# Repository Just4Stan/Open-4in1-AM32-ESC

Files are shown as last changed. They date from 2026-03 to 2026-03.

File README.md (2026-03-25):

# Open 4-in-1 AM32 ESC

An open-source 4-in-1 ESC for FPV drones. Runs [AM32](https://github.com/AlkaMotors/AM32-MultiRotor-ESC-firmware) firmware, works with Betaflight over DShot. Designed in KiCad, ready to order from JLCPCB.

I made a video explaining how it works: https://www.youtube.com/watch?v=TwAmmPxOpTM




## Specs

| Parameter | Value |
|---|---|
| Firmware | AM32 |
| Input voltage | 3-6S LiPo (11.1-25.2V) |
| Continuous current | 35A per channel |
| MCU | AT32F421G8U7 (ARM Cortex-M4, 120MHz) |
| Gate driver | NSG2065Q (3-phase, FD6288Q-compatible) |
| MOSFETs | SP40N03GNJ (40V, 2.9mΩ) — optional FDMC8010DC (30V, 1.28mΩ) for premium builds |
| Current sensing | INA186A3IDCKR (100V/V) + 0.2mOhm shunt (165A max) |
| Protocol | DShot (Betaflight compatible) |
| Power supply | LMR51420YDDCR buck + TLV76733DRVR LDO |
| Connector | JST SM08B-SRSS-TB (Betaflight 8-pin standard) |
| PCB | 6-layer, 1oz copper, designed for JLCPCB PCBA |

## Alternative Components

The gate driver footprint is compatible with the entire FD6288Q clone family (27,000+ units combined stock across 7+ manufacturers) and the TI DRV8300. No PCB changes needed for any of them. Multiple pin-compatible MOSFET options are also available, including the FDMC8010DC (30V, 1.28mΩ) as a premium low-resistance option — 36% lower total phase resistance at the cost of reduced voltage headroom (7S max vs 8S+) and higher per-unit cost.

See [ALTERNATIVES.md](ALTERNATIVES.md) for the full list of pin-compatible gate drivers and MOSFETs with LCSC part numbers, specs, and stock levels.

## How it's built

The schematic is split into a main sheet and a sub-sheet that's reused 4 times — one per ESC channel.

The main sheet (`4in1ESC.kicad_sch`) has the power supply, current sensing, and the 8-pin connector. Each ESC channel (`ESC.kicad_sch`) has:
- AT32F421G8U7 running AM32 firmware
- NSG2065Q 3-phase gate driver with bootstrap caps
- 6x SP40N03GNJ MOSFETs in 3 half-bridges
- Back-EMF feedback network for sensorless commutation

## Project structure

```
4in1ESC.kicad_sch     Main schematic (power, sensing, connector)
ESC.kicad_sch         Single ESC channel (used 4x)
4in1ESC.kicad_pcb     PCB layout
4in1ESC.pretty/       Custom footprints
4in1ESC.3dshapes/     3D models (STEP files)
components.kicad_sym  Custom symbols (gate driver, connector, etc.)
datasheets/           Component datasheets
licensing/            Branding and third-party notices
tools/                Analysis scripts
```

## License

Licensed under [CERN-OHL-S-2.0](https://ohwr.org/cern_ohl_s_v2.txt). See [LICENSE](LICENSE) and [licensing/](licensing/) for branding and third-party notices.

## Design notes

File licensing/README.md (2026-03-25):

# Licensing Notes

This folder collects the repository-specific licensing and branding notes that sit alongside the root [LICENSE](../LICENSE) file.

Repository scope:

- Open 4-in-1 AM32 ESC hardware design files
- local footprints, symbols, and manufacturing data included in this repository

Primary project hardware license:

- `CERN-OHL-S-2.0` for the primary Open 4-in-1 ESC design and associated original project files

Related notes:

- [TRADEMARKS.md](TRADEMARKS.md) for branding and source-identifying use
- [THIRD_PARTY.md](THIRD_PARTY.md) for bundled upstream asset notices

The main `LICENSE` stays at the repository root so GitHub can detect the primary project license correctly.

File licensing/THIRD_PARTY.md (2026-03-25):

# Third-Party Assets

This repository's main hardware design is licensed under `CERN-OHL-S-2.0`, but some bundled assets may retain their own upstream notices or licenses.

Known third-party-licensed asset observed in the current repo state:

- `4in1ESC.3dshapes/QFN-28_L4.0-W4.0-P0.40-TL-EP2.4.step`
  - contains an embedded GNU General Public License notice in the file header

Practical rule:

- embedded upstream notices in individual third-party files remain relevant for those files
- the repository-level hardware license does not erase or replace those upstream notices

If more third-party library assets are intentionally bundled later, document them here.

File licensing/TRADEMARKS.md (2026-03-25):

# Trademarks And Branding

The primary Open 4-in-1 ESC hardware design in this repository is licensed under `CERN-OHL-S-2.0`.

Some bundled third-party assets may carry separate upstream notices. See [THIRD_PARTY.md](THIRD_PARTY.md).

That hardware license does **not** grant permission to use any project names, logos, packaging, product branding, or other source-identifying presentation from this repository in a way that implies official status, endorsement, certification, or authorization.

This means you may:

- make, modify, and sell hardware based on the licensed design files, subject to the repository license
- use factual, non-confusing descriptive statements about compatibility or design origin

This means you may not, without separate written permission:

- present your product as an official or authorized version of this project
- use project logos or branded packaging
- market your product in a way that is likely to confuse customers about who made it, tested it, certified it, or supports it

Examples of descriptive use that are generally acceptable:

- `based on the Open 4-in-1 AM32 ESC design`
- `compatible with the 20x20 Open 4-in-1 AM32 ESC layout`

Any permission to use branding for an official product, reseller arrangement, or certification program is separate from the open hardware license.

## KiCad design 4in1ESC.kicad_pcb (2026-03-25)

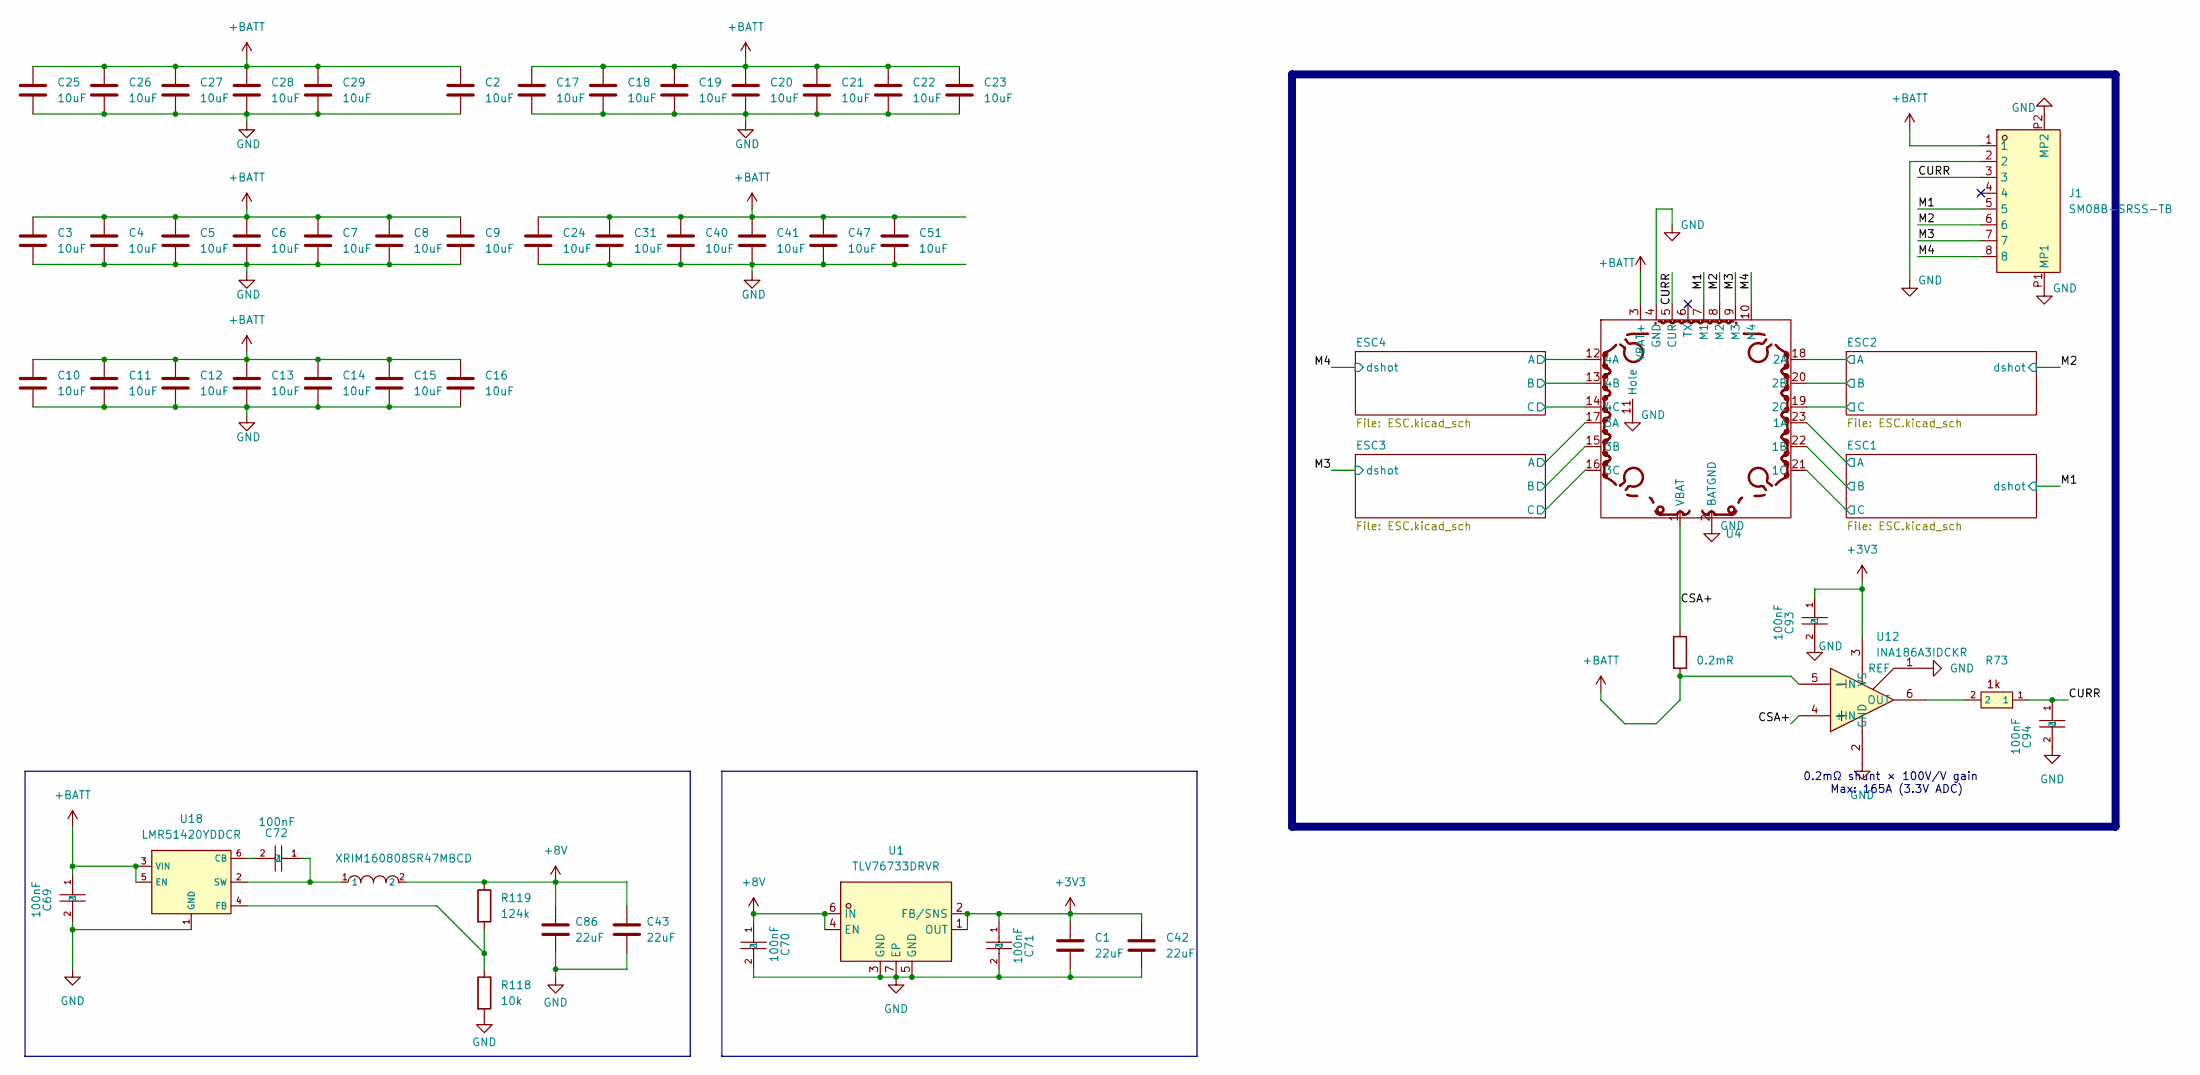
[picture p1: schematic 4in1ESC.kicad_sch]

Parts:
C1, C42: 22uF; C_0402_1005Metric; LCSC C105226
C2, C3, C4, C5, C6, C7, C8, C9, C10, C11, C12, C13, C14, C15, C16, C17, C18, C19, C20, C21, C22, C23, C24, C25, C26, C27, C28, C29, C31, C40, C41, C47, C51: 10uF; C_0805_2012Metric; LCSC C2932476
C43, C86: 22uF; C_0603_1608Metric; LCSC C2762594
C69, C70, C71, C72, C93, C94: 100nF; C_0201_0603Metric; LCSC C181043
J1: SM08B-SRSS-TB; JST_SM08B-SRSS-TB; LCSC C160407
R73: 1k; C_0201_0603Metric; LCSC C270365
R118: 10k; C_0201_0603Metric; LCSC C106225
R119: 124k; R_0201_0603Metric; LCSC C423759
Rsense1: 0.2mR; R_2512_6332Metric; LCSC C695806
U1: TLV76733DRVR; WSON-6_L2.0-W2.0-P0.65-TL-EP; LCSC C2848334
U4: 4in1ESC
U5: XRIM160808SR47MBCD; IND-SMD_L1.6-W0.8_FTC160865SR47MBCA; LCSC C48391583
U12: INA186A3IDCKR; SOT-363_SC-70-6; LCSC C2058245
U18: LMR51420YDDCR; SOT-23-6_L2.9-W1.6-P0.95-LS2.9-BL; LCSC C7296200

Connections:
+3V3: C1.2, C42.2, C71.1, C93.1, U1.1 (OUT), U1.2 (FB/SNS), U12.3 (VS); also elsewhere on the board
+8V: C43.1, C70.1, C86.1, R119.1, U1.4 (EN), U1.6 (IN), U5.2; also elsewhere on the board
+BATT: C2.1, C3.1, C4.1, C5.1, C6.1, C7.1, C8.1, C9.1, C10.1, C11.1, C12.1, C13.1, C14.1, C15.1, C16.1, C17.1, C18.1, C19.1, C20.1, C21.1, C22.1, C23.1, C24.1, C25.1, C26.1, C27.1, C28.1, C29.1, C31.1, C40.1, C41.1, C47.1, C51.1, C69.1, J1.1, Rsense1.2, U4.3 (VBAT+), U12.5 (-IN), U18.3 (VIN), U18.5 (EN); also elsewhere on the board
/CSA+: Rsense1.1, U4.1 (VBAT), U12.4 (+IN)
/CURR: C94.1, J1.3, R73.1, U4.5 (CUR)
/ESC1/MotorA: U4.23 (1A); also elsewhere on the board
/ESC1/MotorB: U4.22 (1B); also elsewhere on the board
/ESC1/MotorC: U4.21 (1C); also elsewhere on the board
/ESC2/MotorA: U4.18 (2A); also elsewhere on the board
/ESC2/MotorB: U4.20 (2B); also elsewhere on the board
/ESC2/MotorC: U4.19 (2C); also elsewhere on the board
/ESC3/MotorA: U4.17 (3A); also elsewhere on the board
/ESC3/MotorB: U4.15 (3B); also elsewhere on the board
/ESC3/MotorC: U4.16 (3C); also elsewhere on the board
/ESC4/MotorA: U4.12 (4A); also elsewhere on the board
/ESC4/MotorB: U4.13 (4B); also elsewhere on the board
/ESC4/MotorC: U4.14 (4C); also elsewhere on the board
/M1: J1.5, U4.7 (M1); also elsewhere on the board
/M2: J1.6, U4.8 (M2); also elsewhere on the board
/M3: J1.7, U4.9 (M3); also elsewhere on the board
/M4: J1.8, U4.10 (M4); also elsewhere on the board
GND: C1.1, C2.2, C3.2, C4.2, C5.2, C6.2, C7.2, C8.2, C9.2, C10.2, C11.2, C12.2, C13.2, C14.2, C15.2, C16.2, C17.2, C18.2, C19.2, C20.2, C21.2, C22.2, C23.2, C24.2, C25.2, C26.2, C27.2, C28.2, C29.2, C31.2, C40.2, C41.2, C42.1, C43.2, C47.2, C51.2, C69.2, C70.2, C71.2, C86.2, C93.2, C94.2, J1.2, J1.P1 (MP1), J1.P2 (MP2), R118.2, U1.3 (GND), U1.5 (GND), U1.7 (EP), U4.2 (BATGND), U4.4 (GND), U4.11 (Hole), U12.1 (REF), U12.2 (GND), U18.1 (GND); also elsewhere on the board
unnamed: R73.2, U12.6 (OUT)
unnamed: C72.2, U18.6 (CB)
unnamed: R118.1, R119.2, U18.4 (FB)
unnamed: C72.1, U5.1, U18.2 (SW)

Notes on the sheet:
0.2mΩ shunt × 100V/V gain Max: 165A (3.3V ADC)

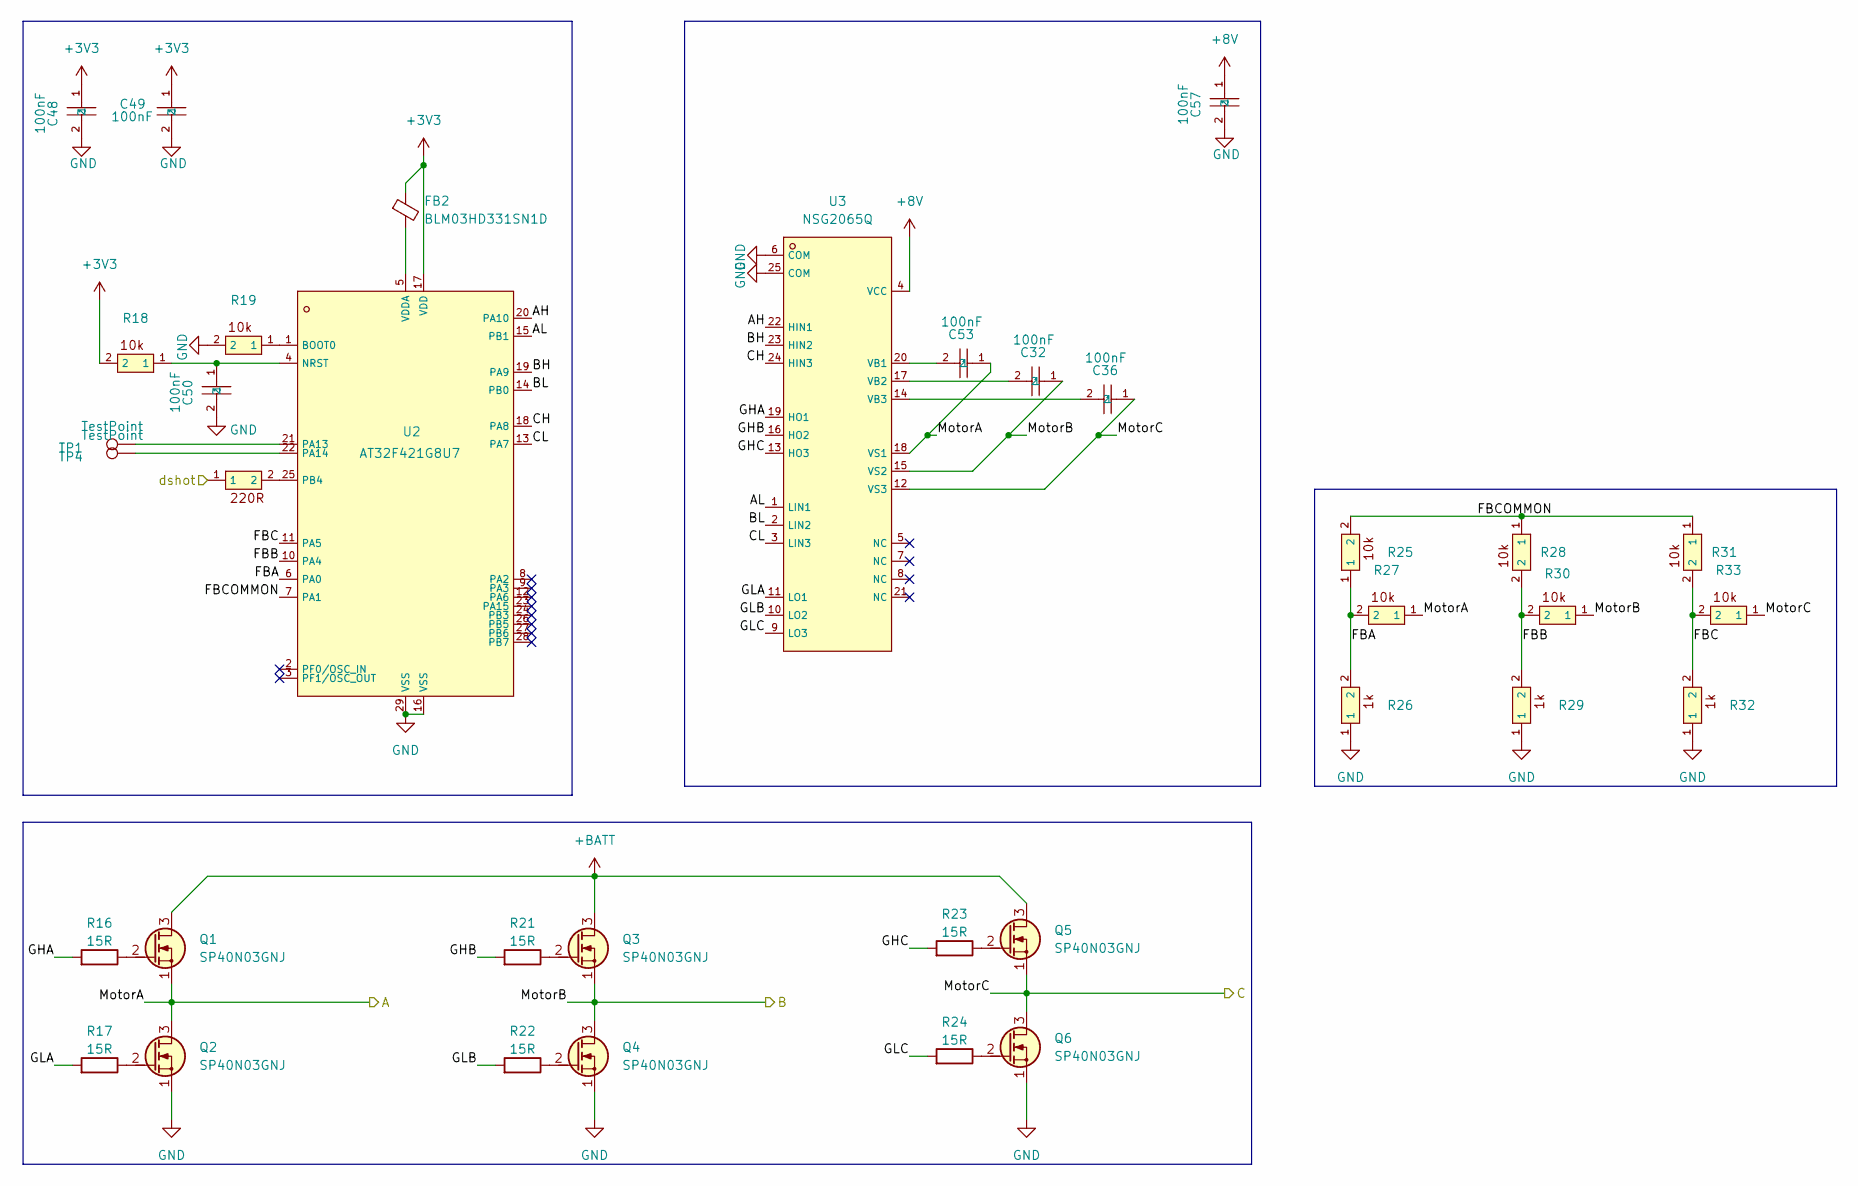
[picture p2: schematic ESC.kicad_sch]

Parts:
C32, C36, C53: 100nF; C_0402_1005Metric; LCSC C307331
C48, C49, C50, C57: 100nF; C_0201_0603Metric; LCSC C181043
FB2: BLM03HD331SN1D; L_0201_0603Metric; LCSC C440127
Q1, Q2, Q3, Q4, Q5, Q6: SP40N03GNJ; POWERPAK-1212-8_L3.0-W3.0-P0.65-LS3.3-BL; LCSC C22466709
R16, R17, R21, R22, R23, R24: 15R; C_0201_0603Metric; LCSC C473542
R18, R19, R25, R27, R28, R30, R31, R33: 10k; C_0201_0603Metric; LCSC C106225
R20: 220R; R_0201_0603Metric; LCSC C226468
R26, R29, R32: 1k; C_0201_0603Metric; LCSC C270365
TP1, TP4: TestPoint; TestPoint_Pad_D1.0mm
U2: AT32F421G8U7; QFN-28_L4.0-W4.0-P0.40-TL-EP2.4; LCSC C2765098
U3: NSG2065Q; QFN-24_L4.0-W4.0-P0.50-TL-EP2.8; LCSC C41414478

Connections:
+3V3: C48.1, C49.1, FB2.1, R18.2, U2.17 (VDD); also elsewhere on the board
+8V: C57.1, U3.4 (VCC); also elsewhere on the board
+BATT: Q1.3 (D), Q3.3 (D), Q5.3 (D); also elsewhere on the board
/ESC1/AH: U2.20 (PA10), U3.22 (HIN1)
/ESC1/AL: U2.15 (PB1), U3.1 (LIN1)
/ESC1/BH: U2.19 (PA9), U3.23 (HIN2)
/ESC1/BL: U2.14 (PB0), U3.2 (LIN2)
/ESC1/CH: U2.18 (PA8), U3.24 (HIN3)
/ESC1/CL: U2.13 (PA7), U3.3 (LIN3)
/ESC1/FBA: R25.1, R26.2, R27.2, U2.6 (PA0)
/ESC1/FBB: R28.2, R29.2, R30.2, U2.10 (PA4)
/ESC1/FBC: R31.2, R32.2, R33.2, U2.11 (PA5)
/ESC1/FBCOMMON: R25.2, R28.1, R31.1, U2.7 (PA1)
/ESC1/GHA: R16.1, U3.19 (HO1)
/ESC1/GHB: R21.1, U3.16 (HO2)
/ESC1/GHC: R23.1, U3.13 (HO3)
/ESC1/GLA: R17.1, U3.11 (LO1)
/ESC1/GLB: R22.1, U3.10 (LO2)
/ESC1/GLC: R24.1, U3.9 (LO3)
/ESC1/MotorA: C53.1, Q1.1 (S), Q2.3 (D), R27.1, U3.18 (VS1); also elsewhere on the board
/ESC1/MotorB: C32.1, Q3.1 (S), Q4.3 (D), R30.1, U3.15 (VS2); also elsewhere on the board
/ESC1/MotorC: C36.1, Q5.1 (S), Q6.3 (D), R33.1, U3.12 (VS3); also elsewhere on the board
/M1: R20.1; also elsewhere on the board
GND: C48.2, C49.2, C50.2, C57.2, Q2.1 (S), Q4.1 (S), Q6.1 (S), R19.2, R26.1, R29.1, R32.1, U2.16 (VSS), U2.29 (VSS), U3.6 (COM), U3.25 (COM); also elsewhere on the board
unnamed: Q1.2 (G), R16.2
unnamed: Q2.2 (G), R17.2
unnamed: Q3.2 (G), R21.2
unnamed: Q4.2 (G), R22.2
unnamed: Q5.2 (G), R23.2
unnamed: Q6.2 (G), R24.2
unnamed: R19.1, U2.1 (BOOT0)
unnamed: C50.1, R18.1, U2.4 (NRST)
unnamed: TP1.1, U2.21 (PA13)
unnamed: TP4.1, U2.22 (PA14)
unnamed: R20.2, U2.25 (PB4)
unnamed: FB2.2, U2.5 (VDDA)
unnamed: C53.2, U3.20 (VB1)
unnamed: C32.2, U3.17 (VB2)
unnamed: C36.2, U3.14 (VB3)

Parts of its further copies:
C33, C34, C35, C37, C38, C39, C59, C73, C83: 100nF; C_0402_1005Metric; LCSC C307331
C44, C45, C46, C63, C64, C65, C66, C77, C78, C79, C80, C88: 100nF; C_0201_0603Metric; LCSC C181043
FB1, FB3, FB4: BLM03HD331SN1D; L_0201_0603Metric; LCSC C440127
Q7, Q8, Q9, Q10, Q11, Q12, Q13, Q14, Q15, Q16, Q17, Q18, Q19, Q20, Q21, Q22, Q23, Q24: SP40N03GNJ; POWERPAK-1212-8_L3.0-W3.0-P0.65-LS3.3-BL; LCSC C22466709
R1, R2, R6, R7, R8, R9, R37, R38, R42, R43, R44, R45, R55, R56, R60, R61, R62, R63: 15R; C_0201_0603Metric; LCSC C473542
R3, R4, R10, R12, R13, R15, R34, R36, R39, R40, R46, R48, R49, R51, R52, R54, R57, R58, R64, R66, R67, R69, R70, R72: 10k; C_0201_0603Metric; LCSC C106225
R5, R41, R59: 220R; R_0201_0603Metric; LCSC C226468
R11, R14, R35, R47, R50, R53, R65, R68, R71: 1k; C_0201_0603Metric; LCSC C270365
TP2, TP3, TP5, TP6, TP7, TP8: TestPoint; TestPoint_Pad_D1.0mm
U6, U8, U10: AT32F421G8U7; QFN-28_L4.0-W4.0-P0.40-TL-EP2.4; LCSC C2765098
U7, U9, U11: NSG2065Q; QFN-24_L4.0-W4.0-P0.50-TL-EP2.8; LCSC C41414478

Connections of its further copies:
+3V3: C44.1, C45.1, C64.1, C65.1, C78.1, C79.1, FB1.1, FB3.1, FB4.1, R3.2, R39.2, R57.2, U6.17 (VDD), U8.17 (VDD), U10.17 (VDD); also elsewhere on the board
+8V: C63.1, C77.1, C88.1, U7.4 (VCC), U9.4 (VCC), U11.4 (VCC); also elsewhere on the board
+BATT: Q7.3 (D), Q9.3 (D), Q11.3 (D), Q13.3 (D), Q15.3 (D), Q17.3 (D), Q19.3 (D), Q21.3 (D), Q23.3 (D); also elsewhere on the board
/ESC2/AH: U6.20 (PA10), U7.22 (HIN1)
/ESC2/AL: U6.15 (PB1), U7.1 (LIN1)
/ESC2/BH: U6.19 (PA9), U7.23 (HIN2)
/ESC2/BL: U6.14 (PB0), U7.2 (LIN2)
/ESC2/CH: U6.18 (PA8), U7.24 (HIN3)
/ESC2/CL: U6.13 (PA7), U7.3 (LIN3)
/ESC2/FBA: R10.1, R11.2, R12.2, U6.6 (PA0)
/ESC2/FBB: R13.2, R14.2, R15.2, U6.10 (PA4)
/ESC2/FBC: R34.2, R35.2, R36.2, U6.11 (PA5)
/ESC2/FBCOMMON: R10.2, R13.1, R34.1, U6.7 (PA1)
/ESC2/GHA: R1.1, U7.19 (HO1)
/ESC2/GHB: R6.1, U7.16 (HO2)
/ESC2/GHC: R8.1, U7.13 (HO3)
/ESC2/GLA: R2.1, U7.11 (LO1)
/ESC2/GLB: R7.1, U7.10 (LO2)
/ESC2/GLC: R9.1, U7.9 (LO3)
/ESC2/MotorA: C59.1, Q7.1 (S), Q8.3 (D), R12.1, U7.18 (VS1); also elsewhere on the board
/ESC2/MotorB: C33.1, Q9.1 (S), Q10.3 (D), R15.1, U7.15 (VS2); also elsewhere on the board
/ESC2/MotorC: C37.1, Q11.1 (S), Q12.3 (D), R36.1, U7.12 (VS3); also elsewhere on the board
/ESC3/AH: U8.20 (PA10), U9.22 (HIN1)
/ESC3/AL: U8.15 (PB1), U9.1 (LIN1)
/ESC3/BH: U8.19 (PA9), U9.23 (HIN2)
/ESC3/BL: U8.14 (PB0), U9.2 (LIN2)
/ESC3/CH: U8.18 (PA8), U9.24 (HIN3)
/ESC3/CL: U8.13 (PA7), U9.3 (LIN3)
/ESC3/FBA: R46.1, R47.2, R48.2, U8.6 (PA0)
/ESC3/FBB: R49.2, R50.2, R51.2, U8.10 (PA4)
/ESC3/FBC: R52.2, R53.2, R54.2, U8.11 (PA5)
/ESC3/FBCOMMON: R46.2, R49.1, R52.1, U8.7 (PA1)
/ESC3/GHA: R37.1, U9.19 (HO1)
/ESC3/GHB: R42.1, U9.16 (HO2)
/ESC3/GHC: R44.1, U9.13 (HO3)
/ESC3/GLA: R38.1, U9.11 (LO1)
/ESC3/GLB: R43.1, U9.10 (LO2)
/ESC3/GLC: R45.1, U9.9 (LO3)
/ESC3/MotorA: C73.1, Q13.1 (S), Q14.3 (D), R48.1, U9.18 (VS1); also elsewhere on the board
/ESC3/MotorB: C34.1, Q15.1 (S), Q16.3 (D), R51.1, U9.15 (VS2); also elsewhere on the board
/ESC3/MotorC: C38.1, Q17.1 (S), Q18.3 (D), R54.1, U9.12 (VS3); also elsewhere on the board
/ESC4/AH: U10.20 (PA10), U11.22 (HIN1)
/ESC4/AL: U10.15 (PB1), U11.1 (LIN1)
/ESC4/BH: U10.19 (PA9), U11.23 (HIN2)
/ESC4/BL: U10.14 (PB0), U11.2 (LIN2)
/ESC4/CH: U10.18 (PA8), U11.24 (HIN3)
/ESC4/CL: U10.13 (PA7), U11.3 (LIN3)
/ESC4/FBA: R64.1, R65.2, R66.2, U10.6 (PA0)
/ESC4/FBB: R67.2, R68.2, R69.2, U10.10 (PA4)
/ESC4/FBC: R70.2, R71.2, R72.2, U10.11 (PA5)
/ESC4/FBCOMMON: R64.2, R67.1, R70.1, U10.7 (PA1)
/ESC4/GHA: R55.1, U11.19 (HO1)
/ESC4/GHB: R60.1, U11.16 (HO2)
/ESC4/GHC: R62.1, U11.13 (HO3)
/ESC4/GLA: R56.1, U11.11 (LO1)
/ESC4/GLB: R61.1, U11.10 (LO2)
/ESC4/GLC: R63.1, U11.9 (LO3)
/ESC4/MotorA: C83.1, Q19.1 (S), Q20.3 (D), R66.1, U11.18 (VS1); also elsewhere on the board
/ESC4/MotorB: C35.1, Q21.1 (S), Q22.3 (D), R69.1, U11.15 (VS2); also elsewhere on the board
/ESC4/MotorC: C39.1, Q23.1 (S), Q24.3 (D), R72.1, U11.12 (VS3); also elsewhere on the board
/M2: R5.1; also elsewhere on the board
/M3: R41.1; also elsewhere on the board
/M4: R59.1; also elsewhere on the board
GND: C44.2, C45.2, C46.2, C63.2, C64.2, C65.2, C66.2, C77.2, C78.2, C79.2, C80.2, C88.2, Q8.1 (S), Q10.1 (S), Q12.1 (S), Q14.1 (S), Q16.1 (S), Q18.1 (S), Q20.1 (S), Q22.1 (S), Q24.1 (S), R4.2, R11.1, R14.1, R35.1, R40.2, R47.1, R50.1, R53.1, R58.2, R65.1, R68.1, R71.1, U6.16 (VSS), U6.29 (VSS), U7.6 (COM), U7.25 (COM), U8.16 (VSS), U8.29 (VSS), U9.6 (COM), U9.25 (COM), U10.16 (VSS), U10.29 (VSS), U11.6 (COM), U11.25 (COM); also elsewhere on the board
unnamed: Q7.2 (G), R1.2
unnamed: Q8.2 (G), R2.2
unnamed: Q9.2 (G), R6.2
unnamed: Q10.2 (G), R7.2
unnamed: Q11.2 (G), R8.2
unnamed: Q12.2 (G), R9.2
unnamed: Q13.2 (G), R37.2
unnamed: Q14.2 (G), R38.2
unnamed: Q15.2 (G), R42.2
unnamed: Q16.2 (G), R43.2
unnamed: Q17.2 (G), R44.2
unnamed: Q18.2 (G), R45.2
unnamed: Q19.2 (G), R55.2
unnamed: Q20.2 (G), R56.2
unnamed: Q21.2 (G), R60.2
unnamed: Q22.2 (G), R61.2
unnamed: Q23.2 (G), R62.2
unnamed: Q24.2 (G), R63.2
unnamed: R4.1, U6.1 (BOOT0)
unnamed: C46.1, R3.1, U6.4 (NRST)
unnamed: TP2.1, U6.21 (PA13)
unnamed: TP3.1, U6.22 (PA14)
unnamed: R5.2, U6.25 (PB4)
unnamed: FB1.2, U6.5 (VDDA)
unnamed: C59.2, U7.20 (VB1)
unnamed: C33.2, U7.17 (VB2)
unnamed: C37.2, U7.14 (VB3)
unnamed: R40.1, U8.1 (BOOT0)
unnamed: C66.1, R39.1, U8.4 (NRST)
unnamed: TP5.1, U8.21 (PA13)
unnamed: TP6.1, U8.22 (PA14)
unnamed: R41.2, U8.25 (PB4)
unnamed: FB3.2, U8.5 (VDDA)
unnamed: C73.2, U9.20 (VB1)
unnamed: C34.2, U9.17 (VB2)
unnamed: C38.2, U9.14 (VB3)
unnamed: R58.1, U10.1 (BOOT0)
unnamed: C80.1, R57.1, U10.4 (NRST)
unnamed: TP7.1, U10.21 (PA13)
unnamed: TP8.1, U10.22 (PA14)
unnamed: R59.2, U10.25 (PB4)
unnamed: FB4.2, U10.5 (VDDA)
unnamed: C83.2, U11.20 (VB1)
unnamed: C35.2, U11.17 (VB2)
unnamed: C39.2, U11.14 (VB3)

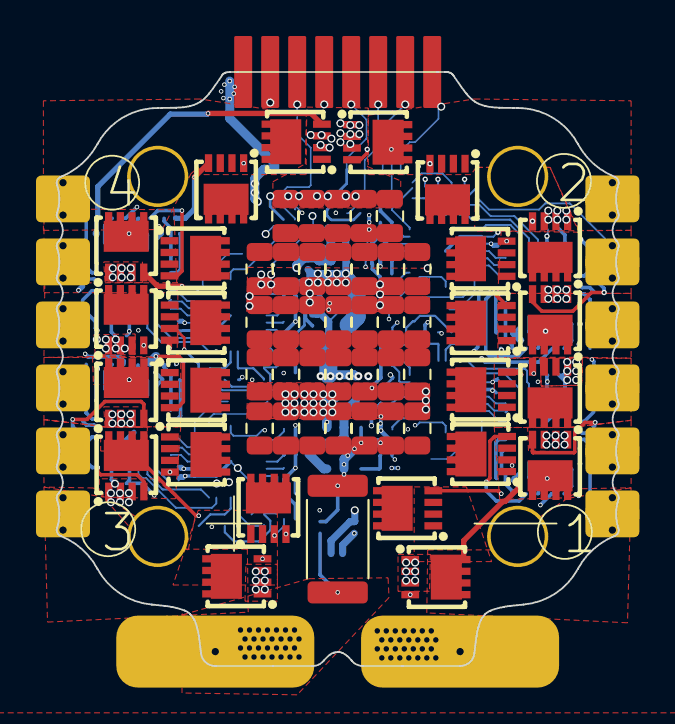
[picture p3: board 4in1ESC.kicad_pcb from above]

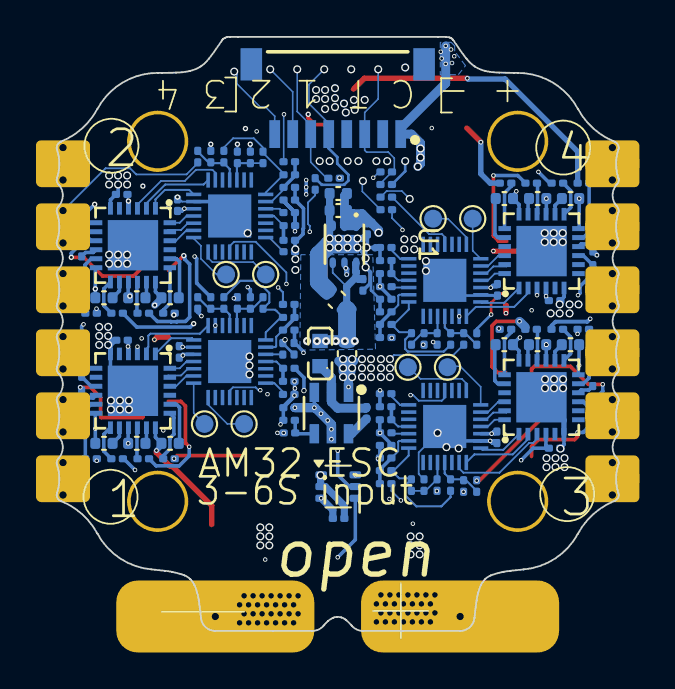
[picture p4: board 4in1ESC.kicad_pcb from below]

Board: 6 copper layers, 31.2 x 33.0 mm, 197 parts (138 on the bottom side), 150 nets.

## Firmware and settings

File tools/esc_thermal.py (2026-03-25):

#!/usr/bin/env python3
"""
4in1 ESC Power Loss & Thermal Calculator

Models AM32 trapezoidal 6-step commutation with steady-state and transient thermal.
Supports both 20x20 and 30x30 ESC variants with datasheet-verified parameters.

Datasheets:
  20x20: SP40N03GNJ (Siliup Ver-1.2) + NSG2065Q (NSIC V1.0), Rg=15Ω
  30x30: SP40N01GHNK (Siliup Ver-1.1) + NSG2065Q (NSIC V1.0), Rg=8Ω
"""

import argparse
import math

# ═══════════════════════════════════════════════════════════════
#  MOSFET profiles — all values from datasheets
# ═══════════════════════════════════════════════════════════════

PROFILES = {
    "20x20": {
        "name":         "20×20  SP40N03GNJ (3×3mm)",
        # ── SP40N03GNJ datasheet (Ver-1.2) ──
        "rds_on":       2.9e-3,     # Ω typ @ Vgs=10V, ID=20A, 25°C
        "rds_on_max":   3.7e-3,     # Ω max
        "rds_tempco":   1.45,       # normalized @ 100°C (p3 curve)
        "rds_tempco_150": 1.70,     # normalized @ 150°C
        "qg_at_10v":    15e-9,      # C  (from gate charge curve p3 @ Vgs=10V)
        "qgd":          5.5e-9,     # C  gate-drain (Miller) charge
        "vgs":          10.0,       # V
        "rg":           15.0,       # Ω  external gate resistor
        "v_plateau":    3.0,        # V  Miller plateau (transfer curve p3)
        # Switching: Qgd / I_gate through Rg
        #   I_on  = (10-3)/15 = 0.47A → tr = 5.5nC/0.47A = 11.7ns
        #   I_off = 3/15      = 0.20A → tf = 5.5nC/0.20A = 27.5ns
        "tr":           11.7e-9,
        "tf":           27.5e-9,
        "vf_body_cold": 0.80,       # V  @ ~30A, 25°C (p4 curve extrapolated)
        "vf_body_hot":  0.65,       # V  @ ~30A, 100°C
        "trr":          14e-9,      # s  (p2)
        "qrr":          23e-9,      # C  (p2)
        "rth_jc":       2.27,       # °C/W (p2)
        "pd_max":       55.0,       # W
        "tj_max":       150.0,      # °C
        # Board
        "board_mm":     20,         # mm mounting pattern
        "board_area":   1030.0,     # mm² actual PCB (~31×33mm, from Edge.Cuts)
        "r_copper":     3.2e-3,     # Ω per phase trace
        "r_shunt":      0.2e-3,     # Ω
        "layers":       6,
        "oz_outer":     1,          # oz copper
        "oz_inner":     0.5,
    },
    "30x30": {
        "name":         "30×30  SP40N01GHNK (5×6mm)",
        # ── SP40N01GHNK datasheet (Ver-1.1) ──
        "rds_on":       1.2e-3,     # Ω typ @ Vgs=10V, ID=20A, 25°C
        "rds_on_max":   1.5e-3,     # Ω max
        "rds_tempco":   1.45,       # normalized @ 100°C (p3 curve)
        "rds_tempco_150": 1.70,     # normalized @ 150°C
        "qg_at_10v":    65e-9,      # C  (from gate charge curve p3 @ Vgs=10V)
        "qgd":          15.5e-9,    # C  gate-drain (Miller) charge
        "vgs":          10.0,       # V
        "rg":           8.0,        # Ω  external gate resistor
        "v_plateau":    3.5,        # V  Miller plateau (transfer curve p3, higher Vth)
        # Switching: Qgd / I_gate through Rg
        #   I_on  = (10-3.5)/8 = 0.81A → tr = 15.5nC/0.81A = 19.1ns
        #   I_off = 3.5/8      = 0.44A → tf = 15.5nC/0.44A = 35.2ns
        "tr":           19.1e-9,
        "tf":           35.2e-9,
        "vf_body_cold": 0.75,       # V  @ ~30A, 25°C (p3 source-drain diode curve)
        "vf_body_hot":  0.60,       # V  @ ~30A, 100°C
        "trr":          29e-9,      # s  (p2)
        "qrr":          113e-9,     # C  (p2) — much higher than SP40N03GNJ
        "rth_jc":       0.96,       # °C/W (p2) — better, larger package
        "pd_max":       130.0,      # W
        "tj_max":       150.0,      # °C
        # Board
        "board_mm":     30,         # mm mounting pattern
        "board_area":   1770.0,     # mm² actual PCB (~42×43mm, from Edge.Cuts)
        "r_copper":     2.0e-3,     # Ω per phase (wider traces, more area)
        "r_shunt":      0.2e-3,     # Ω
        "layers":       6,
        "oz_outer":     1,
        "oz_inner":     0.5,
    },
}

# ─── NSG2065Q gate driver (shared) ───
GATE_DRIVER = {
    "dead_time_typ":  200e-9,   # s  hardware dead time (100-300ns, p6)
    "dead_time_min":  100e-9,
    "dead_time_max":  300e-9,
    "io_source":      1.2,      # A
    "io_sink":        1.5,      # A
}

# ─── Thermal scenarios ───
# h = convective heat transfer coefficient (W/m²·K)
# θ_board = 1 / (h × A_both_sides)
THERMAL_SCENARIOS = {
    "still":        {"h": 15,   "label": "Still air (bench)"},
    "light_flow":   {"h": 50,   "label": "Light prop wash (~3m/s)"},
    "strong_flow":  {"h": 100,  "label": "Strong prop wash (~8m/s)"},
    "direct_blast": {"h": 150,  "label": "Direct motor blast (>10m/s)"},
}

# ─── PCB stackup options for thermal comparison ───
# Copper thickness: 1oz=35µm, 2oz=70µm, 0.5oz=17.5µm
# Thermal conductivity: Cu=385 W/(m·K), FR4=0.3 W/(m·K)
PCB_OPTIONS = {
    "jlcpcb_6L_1oz": {
        "label":    "JLCPCB 6L 1oz/0.5oz (current)",
        "oz_outer": 1.0, "oz_inner": 0.5, "layers": 6,
        "notes":    "Standard, free POFV via-in-pad",
    },
    "jlcpcb_6L_2oz": {
        "label":    "JLCPCB 6L 2oz/2oz (max multilayer)",
        "oz_outer": 2.0, "oz_inner": 2.0, "layers": 6,
        "notes":    "Max Cu at JLCPCB for 6L, ~2x bare board cost",
    },
    "jlcpcb_4L_2oz": {
        "label":    "JLCPCB 4L 2oz/2oz",
        "oz_outer": 2.0, "oz_inner": 2.0, "layers": 4,
        "notes":    "Cheaper than 6L, no free POFV",
    },
    "jlcpcb_6L_3oz": {
        "label":    "JLCPCB 6L 3oz/1oz (industry std ESC)",
        "oz_outer": 3.0, "oz_inner": 1.0, "layers": 6,
        "notes":    "What commercial 35A ESCs use",
    },
    "pcbway_6L_4oz": {
        "label":    "PCBWay 6L 4oz/2oz (heavy Cu)",
        "oz_outer": 4.0, "oz_inner": 2.0, "layers": 6,
        "notes":    "PCBWay supports >2oz on multilayer, premium cost",
    },
}


def board_theta(area_mm2: float, h: float) -> float:
    """Board-to-ambient thermal resistance (°C/W), both sides convecting."""
    area_m2 = area_mm2 * 2.0 * 1e-6
    return 1.0 / (h * area_m2)


def board_thermal_mass(area_mm2: float, layers: int, oz_outer: float, oz_inner: float,
                       board_thickness_mm: float = 1.6) -> float:
    """Board thermal capacitance in J/K.

    Accounts for FR-4 substrate and copper layers.
    FR-4: ρ=1.85 g/cm³, cp=1.1 J/(g·K)
    Cu:   ρ=8.96 g/cm³, cp=0.385 J/(g·K)
    """
    area_cm2 = area_mm2 * 1e-2  # mm² → cm²

    # FR-4 volume (approximate: total thickness minus copper)
    cu_outer_mm = oz_outer * 0.035  # mm per oz
    cu_inner_mm = oz_inner * 0.035 if oz_inner else 0.0175
    n_inner = max(layers - 2, 0)
    total_cu_mm = 2 * cu_outer_mm + n_inner * cu_inner_mm
    fr4_mm = board_thickness_mm - total_cu_mm
    fr4_vol_cm3 = area_cm2 * fr4_mm * 0.1  # cm²×mm→cm³ needs ×0.1
    fr4_mass = fr4_vol_cm3 * 1.85
    fr4_cth = fr4_mass * 1.1

    # Copper volume
    cu_vol_cm3 = area_cm2 * total_cu_mm * 0.1
    cu_mass = cu_vol_cm3 * 8.96
    cu_cth = cu_mass * 0.385

    return fr4_cth + cu_cth


def copper_resistance_scaled(r_base: float, oz_base: float, oz_new: float) -> float:
    """Scale copper trace resistance for different copper weight.
    R ∝ 1/thickness, so doubling oz halves resistance.
    """
    return r_base * oz_base / oz_new


def calc_phase_losses(i: float, v_bus: float, duty: float, f_pwm: float,
                      comp_pwm: bool, dead_time: float, p: dict,
                      r_copper_override: float = None) -> dict:
    """Calculate losses for one active phase pair."""
    rds = p["rds_on"] * p["rds_tempco"]  # hot Rds(on)
    vf = p["vf_body_hot"]
    r_cu = r_copper_override if r_copper_override else p["r_copper"]

    # Conduction
    p_cond_hs = i**2 * rds * duty
    if comp_pwm:
        p_cond_ls = i**2 * rds * (1.0 - duty)
        p_body = 0.0
    else:
        p_cond_ls = 0.0
        p_body = vf * i * (1.0 - duty)
    p_cond_low = i**2 * rds  # LOW-phase FET, 100% on

    # Switching (Miller plateau crossing)
    p_switch = 0.5 * v_bus * i * (p["tr"] + p["tf"]) * f_pwm

    # Dead time (both edges per PWM cycle)
    p_dead = vf * i * dead_time * 2.0 * f_pwm

    # Reverse recovery (Qrr-based model)
    p_rr = p["qrr"] * v_bus * f_pwm

    # Gate drive (HS at f_pwm, LS at commutation freq ~200Hz)
    p_gate = p["qg_at_10v"] * p["vgs"] * f_pwm + p["qg_at_10v"] * p["vgs"] * 200

    # Copper (both phase traces in the current path)
    p_copper = i**2 * r_cu * 2.0

    # Shunt
    p_shunt = i**2 * p["r_shunt"]

    p_fet = p_cond_hs + p_cond_ls + p_body + p_cond_low + p_switch + p_dead + p_rr + p_gate
    p_passive = p_copper + p_shunt
    p_total = p_fet + p_passive

    return {
        "p_cond_hs": p_cond_hs, "p_cond_ls": p_cond_ls, "p_body": p_body,
        "p_cond_low": p_cond_low, "p_switch": p_switch, "p_dead": p_dead,
        "p_rr": p_rr, "p_gate": p_gate, "p_copper": p_copper, "p_shunt": p_shunt,
        "p_fet": p_fet, "p_passive": p_passive, "p_total": p_total,
    }


def transient_time_to_tj(p_board: float, theta_ba: float, c_th: float,
                         tj_max: float, t_ambient: float) -> float:
    """Time (seconds) from ambient to Tj_max under constant power.

    Simple first-order RC model: ΔT(t) = ΔT_ss × (1 - e^(-t/τ))
    τ = C_th × θ_ba
    Returns float('inf') if steady-state ΔT < (Tj_max - T_ambient).
    """
    dt_max = tj_max - t_ambient
    dt_ss = p_board * theta_ba
    if dt_ss <= dt_max:
        return float('inf')  # never reaches Tj_max
    tau = c_th * theta_ba
    return -tau * math.log(1.0 - dt_max / dt_ss)


def print_full_report(profile_key: str, i: float, v_bus: float, duty: float,
                      f_pwm: float, comp_pwm: bool, dead_time: float, n_active: int):
    p = PROFILES[profile_key]
    rds_hot = p["rds_on"] * p["rds_tempco"]
    losses = calc_phase_losses(i, v_bus, duty, f_pwm, comp_pwm, dead_time, p)

    p_board = losses["p_total"] * n_active
    p_motor = v_bus * i * duty * n_active
    eff = p_motor / (p_motor + p_board) * 100 if p_motor > 0 else 0

    print("=" * 70)
    print(f"  4in1 ESC Power Loss Report  —  {p['name']}")
    print(f"  AM32 6-Step Trapezoidal  |  NSG2065Q gate driver")
    print("=" * 70)
    print(f"  Battery voltage:      {v_bus:.1f} V")
    print(f"  Phase current:        {i:.1f} A")
    print(f"  Duty cycle:           {duty*100:.1f}%")
    print(f"  PWM frequency:        {f_pwm/1e3:.0f} kHz")
    print(f"  Dead time:            {dead_time*1e9:.0f} ns  (NSG2065Q HW)")
    print(f"  Comp PWM:             {'ON' if comp_pwm else 'OFF'}")
    print(f"  Gate resistor:        {p['rg']:.0f}Ω  →  tr={p['tr']*1e9:.1f}ns  tf={p['tf']*1e9:.1f}ns")
    print(f"  Rds(on):              {p['rds_on']*1e3:.1f}mΩ cold → {rds_hot*1e3:.1f}mΩ hot (×{p['rds_tempco']})")
    print(f"  Active phases:        {n_active}")
    print("-" * 70)

    print(f"\n  Per phase pair (HS + LS MOSFET + copper):")
    print(f"    HS conduction:     {losses['p_cond_hs']:7.3f} W  (I²×Rds×D)")
    if comp_pwm:
        print(f"    LS sync rect:      {losses['p_cond_ls']:7.3f} W  (I²×Rds×(1-D))")
    else:
        print(f"    Body diode:        {losses['p_body']:7.3f} W  (Vf×I×(1-D))")
    print(f"    LOW-phase FET:     {losses['p_cond_low']:7.3f} W  (I²×Rds, 100%)")
    print(f"    Switching:         {losses['p_switch']:7.3f} W")
    print(f"    Dead time:         {losses['p_dead']:7.3f} W")
    print(f"    Reverse recovery:  {losses['p_rr']:7.3f} W  (Qrr={p['qrr']*1e9:.0f}nC)")
    print(f"    Gate drive:        {losses['p_gate']:7.3f} W")
    print(f"    ────────────────────────────────────────")
    print(f"    FET subtotal:      {losses['p_fet']:7.3f} W")
    print(f"    Copper (×2):       {losses['p_copper']:7.3f} W  ({p['r_copper']*1e3:.1f}mΩ/phase)")
    print(f"    Shunt:             {losses['p_shunt']:7.3f} W")
    print(f"    ────────────────────────────────────────")
    print(f"    Phase total:       {losses['p_total']:7.3f} W")

    print(f"\n  Board totals ({n_active} phases):")
    print(f"    Heat dissipation:  {p_board:7.2f} W")
    print(f"    Motor output:      {p_motor:7.1f} W")
    print(f"    Efficiency:        {eff:7.1f}%")

    # ─── Steady-state thermal ───
    area = p["board_area"]
    c_th = board_thermal_mass(area, p["layers"], p["oz_outer"], p["oz_inner"])

    print(f"\n  Steady-state thermal ({area:.0f}mm² board, {p['layers']}L "
          f"{p['oz_outer']:.0f}oz/{p['oz_inner']}oz):")
    print(f"  {'Scenario':<28s} {'θ':>6s}  {'ΔT':>6s}  {'Tj@25°C':>7s}  {'Tj@40°C':>7s}")
    print(f"  {'-'*62}")

    for key, sc in THERMAL_SCENARIOS.items():
        theta = board_theta(area, sc["h"])
        dt = p_board * theta
        tj25 = 25 + dt
        tj40 = 40 + dt
        w = " !! EXCEED" if tj25 > 150 else " ! HOT" if tj25 > 125 else ""
        print(f"  {sc['label']:<28s} {theta:5.1f}°/W  +{dt:4.0f}°C  {tj25:6.0f}°C  {tj40:6.0f}°C{w}")

    # ─── Transient thermal ───
    print(f"\n  Transient thermal (time to Tj=150°C from 25°C ambient):")
    print(f"  Board thermal mass: {c_th:.2f} J/K")
    print(f"  {'Scenario':<28s} {'τ':>6s}  {'t to 150°C':>10s}")
    print(f"  {'-'*50}")

    for key, sc in THERMAL_SCENARIOS.items():
        theta = board_theta(area, sc["h"])
        tau = c_th * theta
        t_max = transient_time_to_tj(p_board, theta, c_th, 150, 25)
        if t_max == float('inf'):
            t_str = "never"
        elif t_max < 1:
            t_str = f"{t_max*1000:.0f} ms"
        else:
            t_str = f"{t_max:.1f} s"
        print(f"  {sc['label']:<28s} {tau:5.1f}s   {t_str:>10s}")

    # ─── MOSFET limits ───
    p_worst_fet = max(
        losses["p_cond_hs"] + losses["p_switch"] + losses["p_dead"]/2 + losses["p_rr"],
        losses["p_cond_low"] + losses["p_body"] + losses["p_dead"]/2,
    )
    print(f"\n  MOSFET: RθJC={p['rth_jc']:.2f}°C/W  Pd_max={p['pd_max']:.0f}W  Tj_max={p['tj_max']:.0f}°C")
    print(f"  Worst single FET: {p_worst_fet:.2f}W → ΔTjc={p_worst_fet*p['rth_jc']:.1f}°C above pad")
    print("=" * 70)


def sweep(profile_key: str, currents: list, v_bus: float, duty: float,
          f_pwm: float, comp_pwm: bool, dead_time: float, n_active: int):
    p = PROFILES[profile_key]
    area = p["board_area"]
    c_th = board_thermal_mass(area, p["layers"], p["oz_outer"], p["oz_inner"])
    theta_fly = board_theta(area, 100)  # strong prop wash

    print()
    print(f"  {p['name']}  @  {v_bus:.0f}V  {duty*100:.0f}%  {f_pwm/1e3:.0f}kHz  "
          f"comp_pwm={'ON' if comp_pwm else 'OFF'}")
    print(f"  Board: {area:.0f}mm²  θ_propwash={theta_fly:.1f}°/W  C_th={c_th:.2f}J/K")
    print(f"  {'I':>6s}  {'Phase':>7s}  {'Board':>7s}  {'Eff':>5s}  "
          f"{'Tj_fly':>6s}  {'t→150°C':>8s}  {'Rating':>12s}")
    print(f"  {'-'*66}")

    for current in currents:
        losses = calc_phase_losses(current, v_bus, duty, f_pwm, comp_pwm, dead_time, p)
        p_board = losses["p_total"] * n_active
        p_motor = v_bus * current * duty * n_active
        eff = p_motor / (p_motor + p_board) * 100 if p_motor > 0 else 0
        tj_fly = 25 + p_board * theta_fly
        t_max = transient_time_to_tj(p_board, theta_fly, c_th, 150, 25)

        if t_max == float('inf'):
            t_str = "∞"
            if tj_fly < 100:
                rating = "continuous"
            elif tj_fly < 125:
                rating = "continuous*"
            else:
                rating = "marginal"
        elif t_max > 10:
            t_str = f"{t_max:.0f}s"
            rating = "burst OK"
        elif t_max > 3:
            t_str = f"{t_max:.1f}s"
            rating = "burst limit"
        else:
            t_str = f"{t_max:.1f}s"
            rating = "DANGER"

        print(f"  {current:5.0f}A  {losses['p_total']:6.2f}W  {p_board:6.1f}W  "
              f"{eff:4.1f}%  {tj_fly:5.0f}°C  {t_str:>8s}  {rating:>12s}")

    print()
    print("  continuous  = Tj < 100°C steady-state in prop wash")
    print("  continuous* = Tj 100-125°C (hot but survivable)")
    print("  marginal    = Tj 125-150°C (near limit)")
    print("  burst OK    = >10s to Tj_max (typical punch-out)")
    print("  burst limit = 3-10s to Tj_max")
    print()


def compare_boards(v_bus: float, duty: float, f_pwm: float, comp_pwm: bool,
                   dead_time: float, n_active: int):
    """Side-by-side comparison of both ESC variants."""
    currents = [5, 10, 15, 20, 25, 30, 35, 40, 50]

    print()
    print("=" * 78)
    print("  BOARD COMPARISON  —  20×20 vs 30×30")
    print(f"  {v_bus:.0f}V  {duty*100:.0f}% duty  {f_pwm/1e3:.0f}kHz  "
          f"comp_pwm={'ON' if comp_pwm else 'OFF'}  {n_active} phases")
    print("=" * 78)

    for key in ["20x20", "30x30"]:
        p = PROFILES[key]
        area = p["board_area"]
        c_th = board_thermal_mass(area, p["layers"], p["oz_outer"], p["oz_inner"])
        theta_fly = board_theta(area, 100)
        rds_hot = p["rds_on"] * p["rds_tempco"]

        print(f"\n  {p['name']}")
        print(f"  Rds(on)={rds_hot*1e3:.1f}mΩ hot  Rg={p['rg']:.0f}Ω  "
              f"Qrr={p['qrr']*1e9:.0f}nC  RθJC={p['rth_jc']:.2f}°/W")
        print(f"  θ_fly={theta_fly:.1f}°/W  C_th={c_th:.2f}J/K  "
              f"R_cu={p['r_copper']*1e3:.1f}mΩ/phase")
        print(f"  {'I':>6s}  {'Board W':>7s}  {'Eff':>5s}  "
              f"{'Tj_fly':>6s}  {'t→150°C':>8s}")
        print(f"  {'-'*44}")

        for current in currents:
            losses = calc_phase_losses(current, v_bus, duty, f_pwm, comp_pwm, dead_time, p)
            p_board = losses["p_total"] * n_active
            p_motor = v_bus * current * duty * n_active
            eff = p_motor / (p_motor + p_board) * 100 if p_motor > 0 else 0
            tj_fly = 25 + p_board * theta_fly
            t_max = transient_time_to_tj(p_board, theta_fly, c_th, 150, 25)
            t_str = "∞" if t_max == float('inf') else f"{t_max:.1f}s" if t_max < 60 else f"{t_max/60:.0f}m"
            warn = " !!" if tj_fly > 150 else " !" if tj_fly > 125 else ""
            print(f"  {current:5.0f}A  {p_board:6.1f}W  {eff:4.1f}%  "
                  f"{tj_fly:5.0f}°C  {t_str:>8s}{warn}")

    print()


def compare_pcb_options(profile_key: str, i: float, v_bus: float, duty: float,
                        f_pwm: float, comp_pwm: bool, dead_time: float, n_active: int):
    """Show impact of different PCB stackups on thermal performance."""
    p = PROFILES[profile_key]

    print()
    print(f"  PCB stackup comparison for {p['name']} @ {i:.0f}A {v_bus:.0f}V {duty*100:.0f}%")
    print("=" * 78)
    print(f"  {'Option':<38s} {'R_cu':>5s} {'Board W':>7s} {'Tj_fly':>6s} "
          f"{'t→150':>6s} {'Notes'}")
    print(f"  {'-'*76}")

    for opt_key, opt in PCB_OPTIONS.items():
        r_cu = copper_resistance_scaled(p["r_copper"], p["oz_outer"], opt["oz_outer"])
        losses = calc_phase_losses(i, v_bus, duty, f_pwm, comp_pwm, dead_time, p,
                                   r_copper_override=r_cu)
        p_board = losses["p_total"] * n_active
        area = p["board_area"]
        c_th = board_thermal_mass(area, opt["layers"], opt["oz_outer"], opt["oz_inner"])
        theta_fly = board_theta(area, 100)
        tj = 25 + p_board * theta_fly
        t_max = transient_time_to_tj(p_board, theta_fly, c_th, 150, 25)
        t_str = "∞" if t_max == float('inf') else f"{t_max:.1f}s"

        print(f"  {opt['label']:<38s} {r_cu*1e3:4.1f}  {p_board:6.1f}W  "
              f"{tj:5.0f}°C  {t_str:>5s}  {opt['notes']}")

    print()


def main():
    parser = argparse.ArgumentParser(
        description="4in1 ESC power loss calculator (AM32 6-step trapezoidal)",
        formatter_class=argparse.RawDescriptionHelpFormatter,
        epilog="""\
examples:
  %(prog)s -p 20x20 -i 30 -v 16.8 -d 80
  %(prog)s -p 30x30 -i 40 -v 25.2 -d 50 --comp-pwm
  %(prog)s -p 20x20 --sweep 5,10,15,20,25,30,35,40
  %(prog)s --compare -v 16.8 -d 80
  %(prog)s --pcb-options -p 30x30 -i 30 -v 16.8 -d 80
""")
    parser.add_argument("-p", "--profile", choices=["20x20", "30x30"], default="20x20",
                        help="ESC variant (default: 20x20)")
    parser.add_argument("-i", "--current", type=float, default=30.0)
    parser.add_argument("-v", "--voltage", type=float, default=16.8)
    parser.add_argument("-d", "--duty", type=float, default=80.0)
    parser.add_argument("-f", "--pwm-freq", type=float, default=24000)
    parser.add_argument("--dead-time", type=float, default=200e-9)
    parser.add_argument("--comp-pwm", action="store_true")
    parser.add_argument("-n", "--num-active", type=int, default=4)
    parser.add_argument("--sweep", type=str, default=None)
    parser.add_argument("--compare", action="store_true",
                        help="compare 20x20 vs 30x30 side by side")
    parser.add_argument("--pcb-options", action="store_true",
                        help="compare PCB stackup options")

    args = parser.parse_args()
    duty = args.duty / 100.0

    if args.compare:
        compare_boards(args.voltage, duty, args.pwm_freq, args.comp_pwm,
                       args.dead_time, args.num_active)
    elif args.pcb_options:
        compare_pcb_options(args.profile, args.current, args.voltage, duty,
                            args.pwm_freq, args.comp_pwm, args.dead_time, args.num_active)
    elif args.sweep:
        currents = [float(x) for x in args.sweep.split(",")]
        sweep(args.profile, currents, args.voltage, duty, args.pwm_freq,
              args.comp_pwm, args.dead_time, args.num_active)
    else:
        print_full_report(args.profile, args.current, args.voltage, duty,
                          args.pwm_freq, args.comp_pwm, args.dead_time, args.num_active)


if __name__ == "__main__":
    main()

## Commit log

2026-03-09 made it
    [4in1ESC.kicad_pcb, 4in1ESC.kicad_sch, ESC.kicad_sch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]
2026-03-09 Update PCB layer count in README
    Updated PCB layer count from 4-layer to 6-layer.
2026-03-11 Replaced the old ESC Connector with JST-SH series
    [4in1ESC.kicad_pcb, 4in1ESC.kicad_sch]
2026-03-11 Fix library structure: local 3D models, new components, path cleanup
    - Create 4in1ESC.3dshapes/ with all STEP files (previously referenced
    from absolute paths to StingerESC, StingerV3, and gitignored backups)
    - Fix all 3D model paths in footprints and PCB to use ${KIPRJMOD}/4in1ESC.3dshapes/
    - Add TLV76733DRVR (C2848334) symbol + WSON-6 footprint
    - Add INA293A2IDBVR (C1855797) symbol + SOT-23-5 footprint
    - Fix footprint library prefixes in components.kicad_sym (4in1ESC:)
    - Fix reference designators: connector=J, inductor=L
    - Fix NSG2065Q datasheet URL (was pointing to wrong PDF)
    - Fix INA293A2 footprint attribute (through_hole -> smd)
    - Fix TLV76733 3D model offset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
    [4in1ESC.kicad_pcb]
2026-03-11 v0.4 component swap: INA186, TLV76733, JST symbol, ferrite bead
    - Replace INA199A1DCKR with INA186A3IDCKR (C2058245) current sense amp
    - Replace TPS746 with TLV76733DRVR (C2848334) LDO, SNS pin wired to output
    - Add SM08B-SRSS-TB and INA186A3IDCKR symbols to local library
    - Add JST 3D model (CONN-SMD_SR1.00-WS-8P.step) to footprint
    - Add SC-70-6 3D model for INA186
    - Update ferrite bead to BLM03PX121SN1D (C525479) in ESC sub-sheet
    - Schematic ready for routing, DRC errors remain to fix
    [4in1ESC.kicad_sch, ESC.kicad_sch]
2026-03-11 update readme n datasheets
    [4in1ESC.kicad_sch]
2026-03-14 Added many compatibilty and fixed all issues, ready for ordering V1
    [4in1ESC.kicad_pcb, 4in1ESC.kicad_sch]
2026-03-14 final layout
    [4in1ESC.kicad_pcb]
2026-03-16 Parts changes and final production files for V1
    [4in1ESC.kicad_sch, V1_bom.csv, V1_designators.csv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]
2026-03-18 BOM substitutions: replace OOS parts with in-stock alternatives
    - 10kΩ 0201: C473048 → C106225 (Yageo RC0201FR-0710KL, 1.17M stock)
    - 220Ω 0201: C473535 → C226468 (Yageo AC0201FR-07220RL, 21.9k stock)
    - Ferrite bead 0201: C525479 → C440127 (Murata BLM03HD331SN1D 330Ω, 53.6k stock)
    - Buck converter: C5383002 → C7296200 (LMR51420YFDDCR 1.1MHz FPWM)
    - Bulk 10uF caps: C13585 → C2932476 (Samsung CL21A106KBYQNNE 0805 50V)
    - Exclude test points and board outline from BOM
    [4in1ESC.kicad_sch, ESC.kicad_sch]
2026-03-25 Standardize repo: .gitignore, README, license, remove production from tracking
    - Standardize .gitignore to match ecosystem template
    - Update README: fix production refs, add missing dirs, simplify license section
    - Replace LICENSE stub with full CERN-OHL-S-2.0 text
    - Remove production/ from git tracking (generated, re-exportable)
    - Add previously untracked: licensing/, COST_ANALYSIS.md, tools/esc_thermal.py
    - Delete NextPCB artifact (bom_template_nextpcb)
    [4in1ESC.kicad_pcb, 4in1ESC.kicad_sch, ESC.kicad_sch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]
